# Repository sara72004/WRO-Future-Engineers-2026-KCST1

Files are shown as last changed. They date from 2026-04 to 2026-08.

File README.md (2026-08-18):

# ✨ WRO Future Engineers 2026 – Team KCST1: Blaze Autonomous Robot

##  Unleashing Blaze: Precision, Speed, and Innovation in Autonomous Robotics

Welcome to the official repository for **Blaze**, our cutting-edge autonomous robot designed and developed for the **World Robot Olympiad (WRO) 2026 – Future Engineers category**. Blaze is not just a robot; it's a testament to meticulous engineering, innovative problem-solving, and relentless pursuit of excellence. Our mission: to achieve **unparalleled robust, repeatable, and stable navigation** within a dynamic arena, powered by a sophisticated blend of laser-based environmental sensing, advanced steering control, and deterministic decision-making algorithms.

### Why "Blaze"?

Our robot's name, **Blaze**, encapsulates its core attributes and our team's aspirations:

*    **Blazing Speed:** Fast and decisive movement across the competition track.
*    **Blazing Performance:** Strong, stable, and consistent execution under pressure.
*    **Blazing Innovation:** A beacon of engineering ingenuity, pushing the boundaries of autonomous navigation.

Blaze is the culmination of countless hours of iterative design, rigorous testing, and continuous refinement, integrating state-of-the-art mechanical improvements, optimized sensor fusion, and intelligent control logic to deliver a truly competition-winning performance.

:)  *Fun note:* The name "Blaze" was chosen by a doctor ⠮⠺⠊⠎⠑⠍⠁⠝ who has supported and encouraged our team, a small detail that makes the project even more meaningful to us.

##  Meet the Innovators: Team KCST1

<div align="center">

<table>
<tr>
<td align="center">

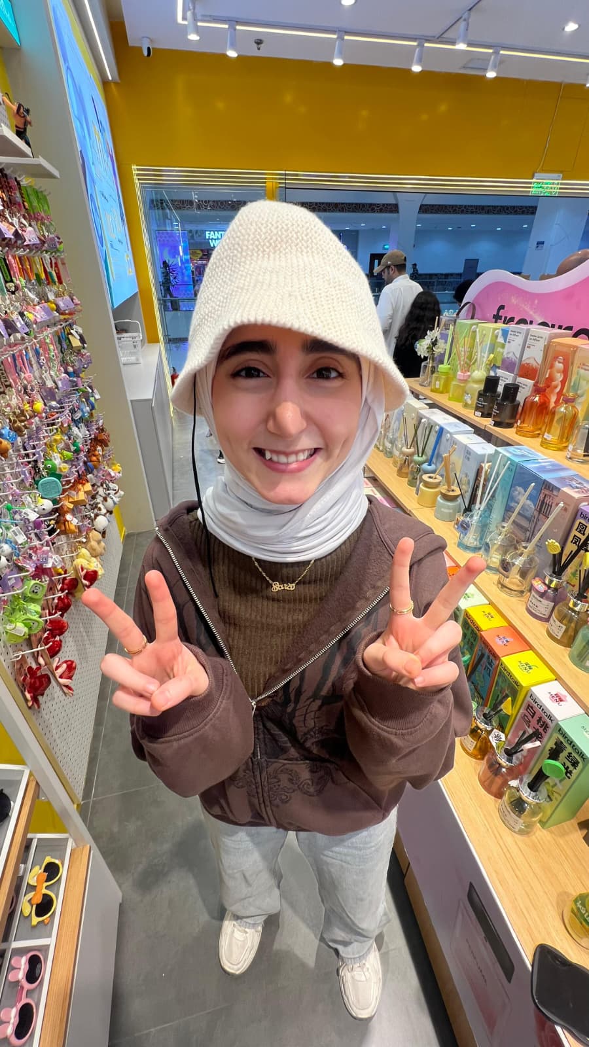
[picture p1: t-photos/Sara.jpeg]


**Sara**  
*Hardware Design, Mechanical Integration, GitHub Management*

</td>

<td align="center">

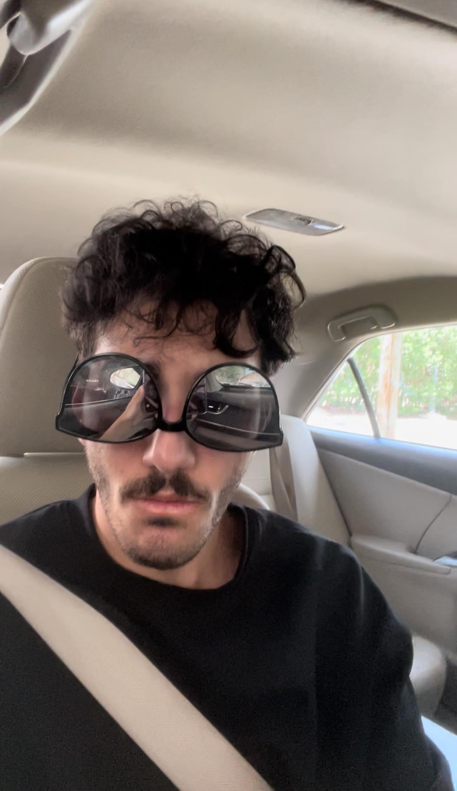
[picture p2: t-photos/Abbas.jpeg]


**Abbas**  
*Software Development, Testing, System Validation*

</td>
</tr>
</table>

</div>

---

###  Our Guiding Light: Coach Eng. Zainab

We extend our deepest gratitude to Eng. Zainab, whose invaluable guidance, unwavering support, and insightful feedback were instrumental in shaping Blaze into the formidable machine it is today.

### Team
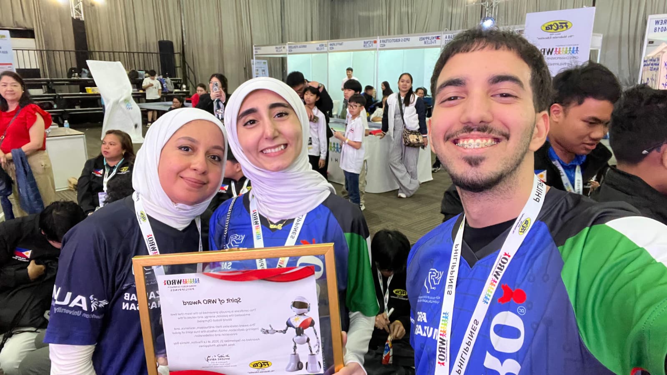
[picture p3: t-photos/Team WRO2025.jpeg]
Team


---

##  Witness Blaze in Action: Demonstration Video

Experience Blaze's autonomous capabilities firsthand:

👉 [WRO Future Engineers 2026 - Team KCST1 Robot Demonstration Video](https://youtu.be/j1B9A54QlEQ )

---

##  The Engineering Imperative: Blaze's Core Objectives

Our primary engineering objective was to construct a robot capable of:

*   **Autonomous Wall & Corner Navigation:** Seamlessly detecting and navigating complex track layouts.
*   **Stable & Responsive Steering:** Maintaining precise control across varying speeds and terrains.
*   **Consistent Lap Completion:** Reliably finishing multiple laps without human intervention.
*   **High Reliability:** Performing flawlessly under the demanding conditions of real-world competition.

---

##  Hardware Architecture: The Foundation of Performance

Blaze's robust hardware architecture is meticulously designed for optimal performance and reliability.

###  The Brain: MATRIX Mini R4 Controller

<div align="center">
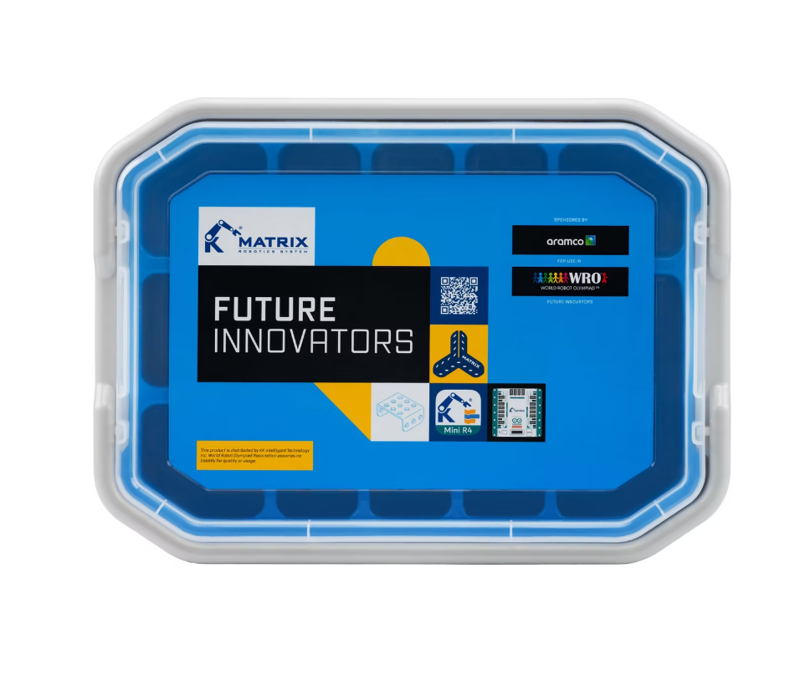
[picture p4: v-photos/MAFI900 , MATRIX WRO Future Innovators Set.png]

</div>

At the heart of Blaze lies the **MATRIX Mini R4 (MAFI900 kit)**, serving as the central processing unit, orchestrating all sensor inputs and motor outputs with precision.

---

###  The Eyes & Ears: Advanced Sensor System

<div align="center">
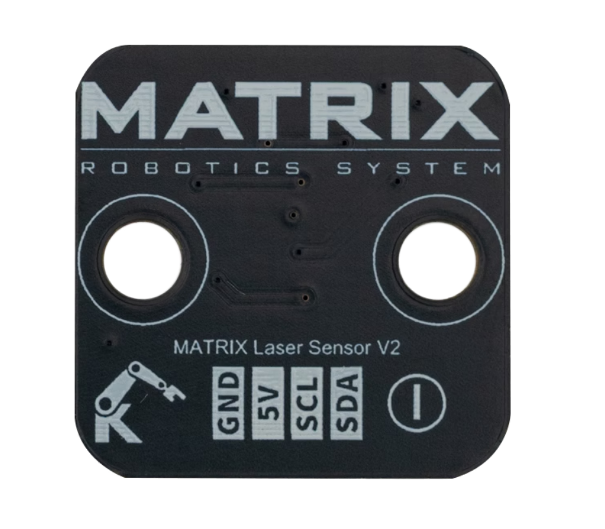
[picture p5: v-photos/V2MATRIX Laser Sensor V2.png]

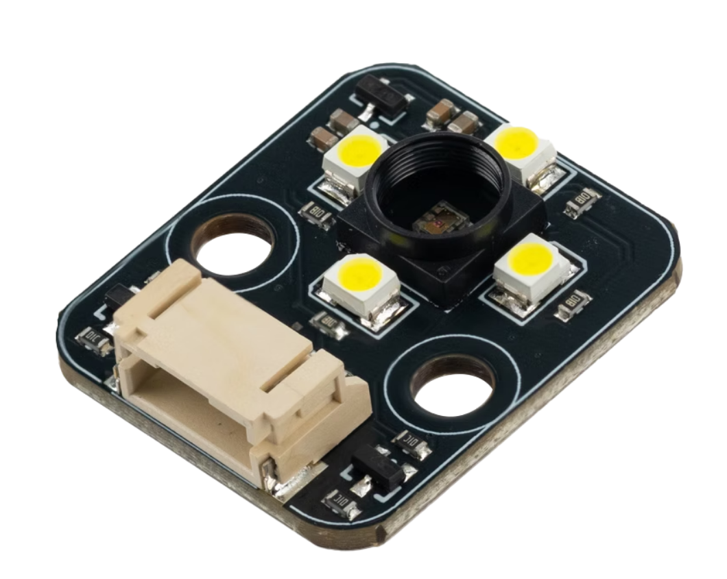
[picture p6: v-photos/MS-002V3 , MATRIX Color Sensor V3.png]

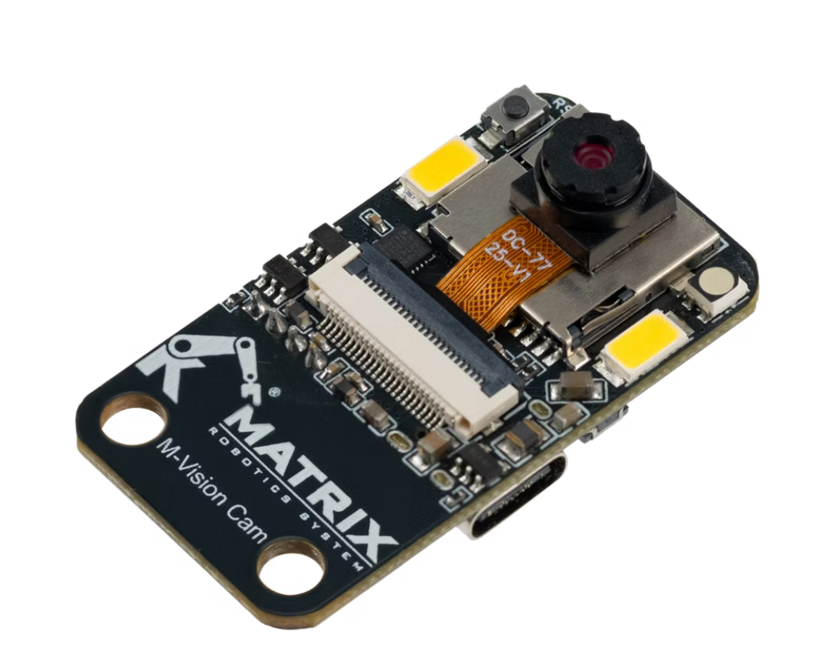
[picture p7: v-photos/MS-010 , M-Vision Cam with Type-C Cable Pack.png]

</div>

Our sensor suite provides Blaze with comprehensive environmental awareness:

*   **3 × MATRIX Laser Sensor V2:** Strategically positioned for superior reliability and consistency in distance measurement, crucial for accurate wall detection and navigation, regardless of lighting conditions.
*   **MATRIX Color Sensor V3:** Utilized for initial track detection and identifying specific colored markers, ensuring precise alignment.
*   **M-Vision Camera (MS-010):** Provides broader environmental awareness, enabling advanced decision-making for obstacle recognition and path planning.

 Laser sensors chosen for reliability and consistency.

---

###  The Muscles: Actuation System

<div align="center">
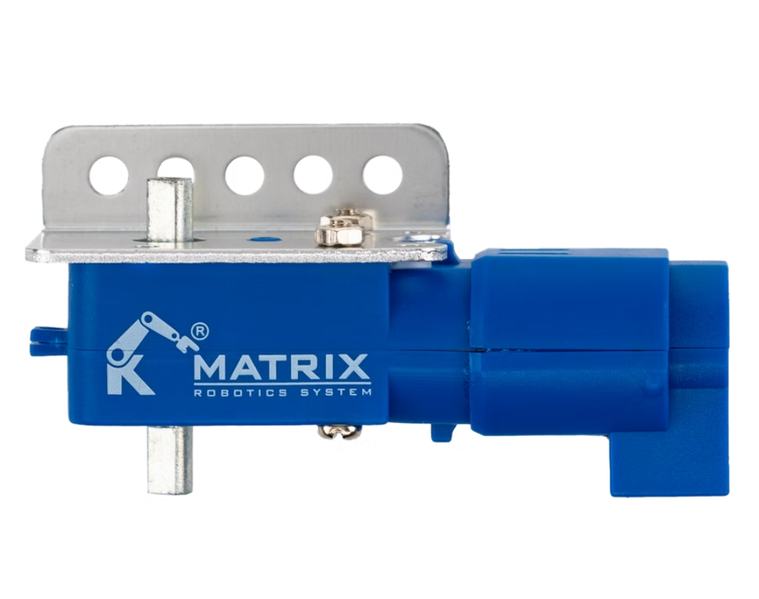
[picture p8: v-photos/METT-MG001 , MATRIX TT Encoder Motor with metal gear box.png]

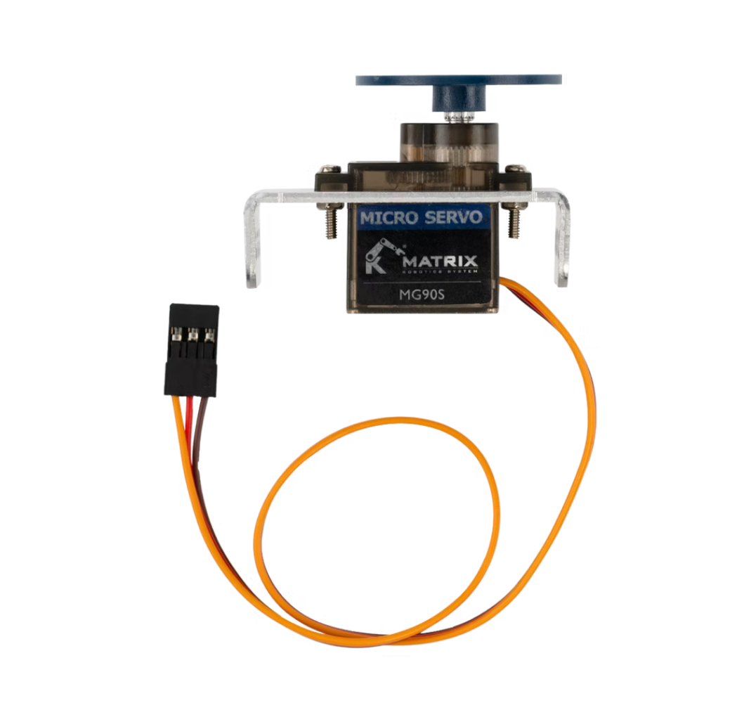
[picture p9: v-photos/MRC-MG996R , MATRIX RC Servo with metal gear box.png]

</div>

*   **TT Encoder Motors (x2):** Deliver precise control over wheel rotation and speed, essential for accurate steering and consistent movement.
*   **MG996R Servo Motor:** Provides high torque and rapid response for dynamic steering adjustments.

---

###  The Grip: Optimized Wheel System

<div align="center">
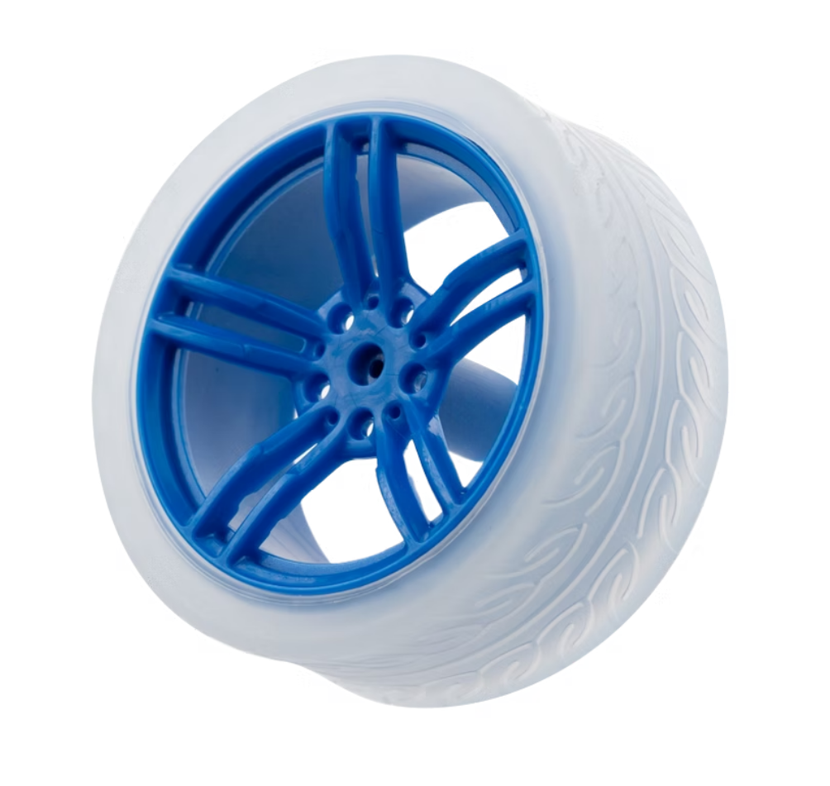
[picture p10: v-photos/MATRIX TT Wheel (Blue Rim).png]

</div>

*   **MATRIX TT Wheels:** Selected for their optimal grip and durability on the competition surface. Extensive testing revealed that a uniform wheel system significantly improves stability and predictability compared to mixed configurations.

 Improved stability after replacing mixed wheels.

---

###  Mechanical Innovation: The Custom 3D Printed Axle

<div align="center">
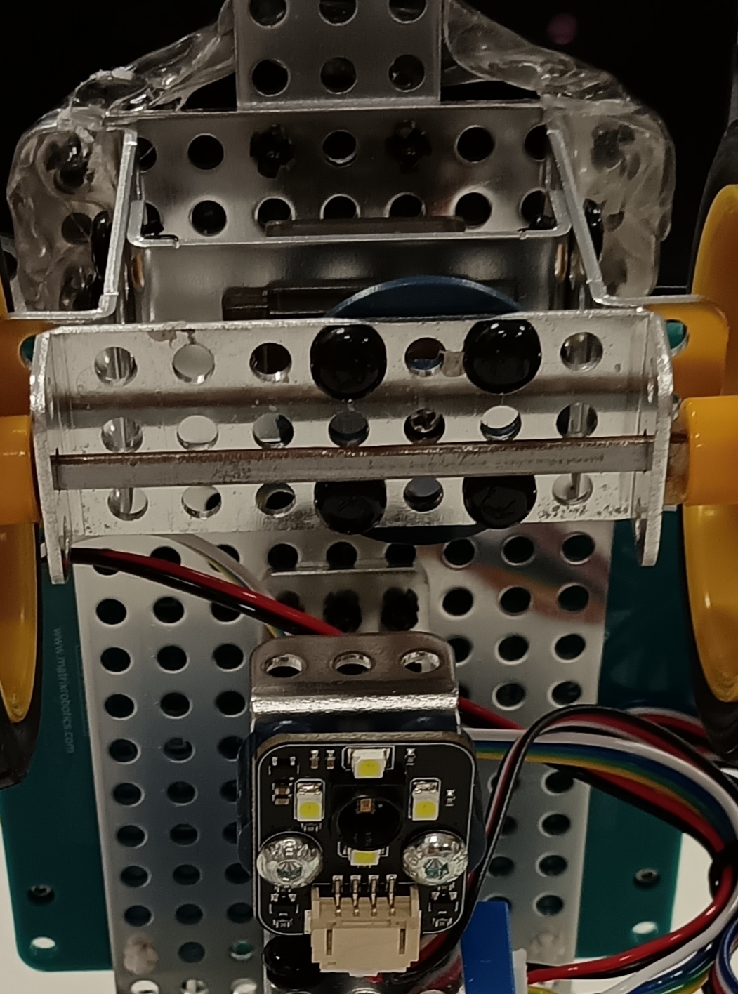
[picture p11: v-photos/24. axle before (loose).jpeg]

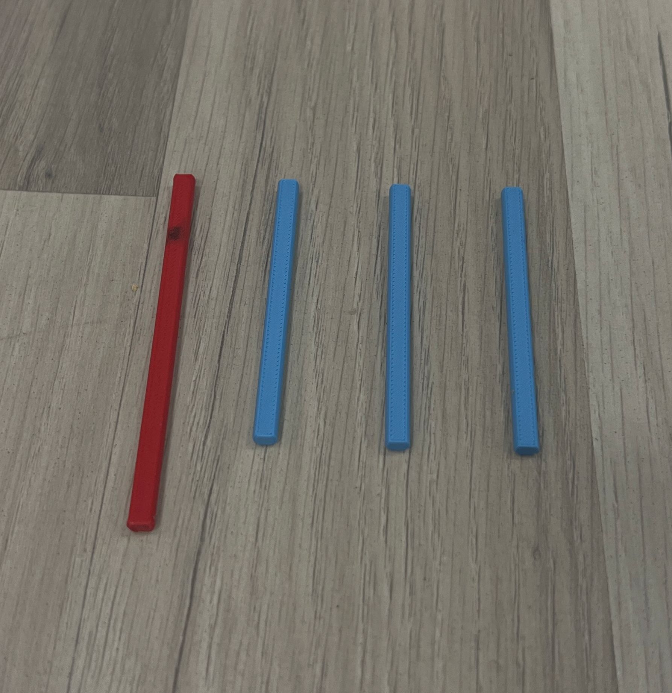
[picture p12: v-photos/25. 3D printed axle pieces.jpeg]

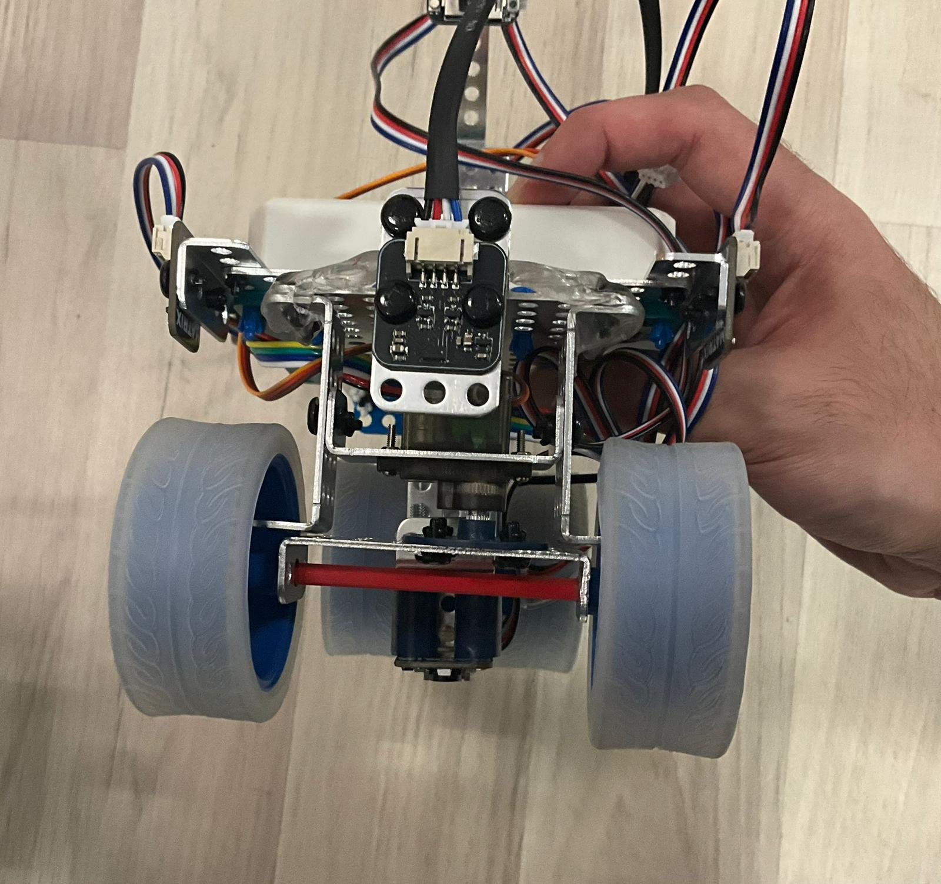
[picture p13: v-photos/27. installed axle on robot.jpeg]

</div>

#### The Challenge:

Early prototypes struggled with a loose axle, leading to unstable steering and compromised accuracy during turns, severely impacting lap times and overall performance.

#### The Breakthrough Solution:

We engineered and implemented a **custom 3D printed axle**. This innovative design provides a secure and precise fit, eliminating play and dramatically enhancing steering stability and control. The CAD files for this critical component are available in the `mechanical/CAD` directory, ensuring full reproducibility.

 Result: A significant leap in steering precision and stability, directly translating to improved navigation and reduced error rates.

---

##  System Architecture Overview

This diagram illustrates the interconnectedness of Blaze's subsystems, from power distribution to sensing and actuation.

<div align="center">
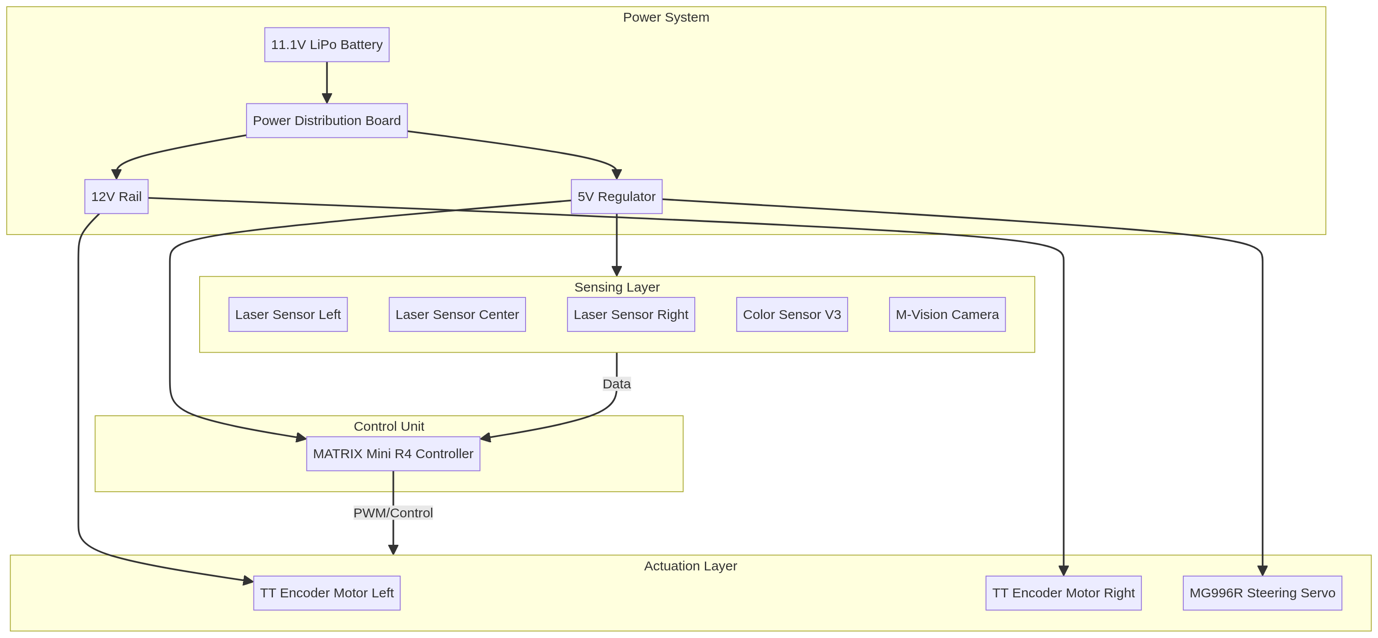
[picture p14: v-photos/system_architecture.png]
  
</div>

---

##  Navigation System Design: From Challenge to Precision

### ❌ The Initial Detour: Color-Based Navigation

<div align="center">
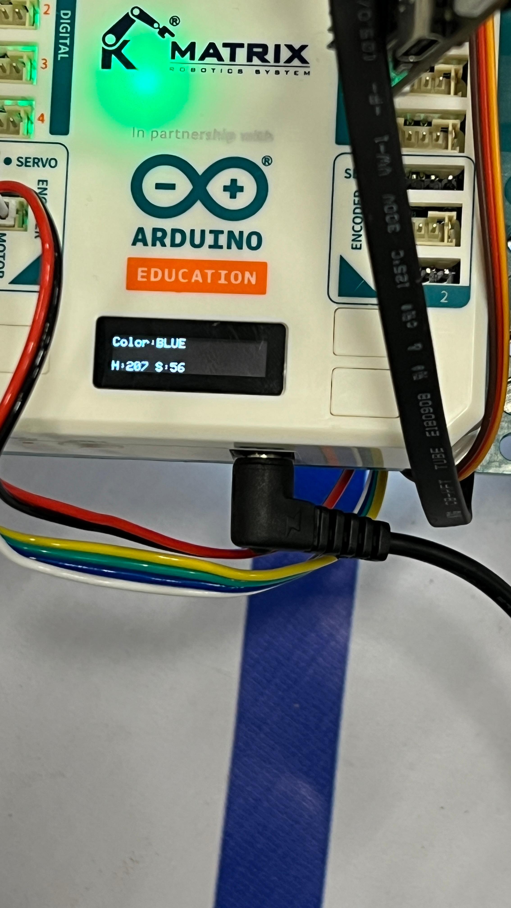
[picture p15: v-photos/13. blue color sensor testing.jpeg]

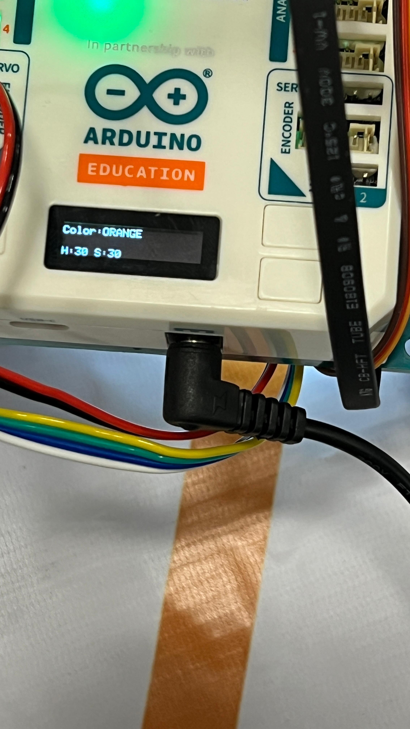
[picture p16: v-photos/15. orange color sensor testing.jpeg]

</div>

Our initial exploration into color-based navigation revealed critical limitations:

*   **Frequent Missed Detections:** Inconsistent recognition of track lines and obstacles, especially at higher speeds.
*   **Lighting Sensitivity:** Performance heavily reliant on ambient light, leading to unpredictable behavior across different environments.
*   **Inconsistent Runs:** High variability in detection resulted in unreliable lap completions.

---

### ✅ The Optimal Path: Laser-Based Navigation

Learning from these challenges, we pivoted to a laser-based system, offering decisive advantages:

*   **Unwavering Reliability:** Consistent and accurate distance readings, independent of surface color or texture.
*   **Environmental Robustness:** Stable operation across diverse lighting conditions, ensuring predictable performance.
*   **Repeatable Precision:** Eliminates variability, leading to highly predictable and repeatable robot behavior.

---

##  Design Trade-offs

We initially considered using color-based navigation due to its simplicity. However, testing revealed sensitivity to lighting conditions and missed detections at higher speeds.

Laser sensors were selected instead because they provide:
- Faster response time
- Consistent readings regardless of lighting
- More reliable wall detection for high-speed navigation
  
---

###  The Direction Locking Strategy

To prevent oscillation and ensure smooth, efficient navigation, we implemented a sophisticated direction locking strategy:

*   The robot's initial turn in any section establishes its intended direction of travel.
*   All subsequent turns within that section are then constrained to follow this established direction.

✔ Result: This strategy effectively eliminates confusion and oscillation, contributing to exceptionally smooth and efficient navigation.

---

##  Software Architecture: The Brains Behind the Blaze

Blaze's software architecture is designed for modularity, flexibility, and robust decision-making, utilizing a state machine approach for clear control flow.

### Software State Machine Diagram

This diagram visualizes the robot's operational states and transitions, providing a clear understanding of its decision-making process.

<div align="center">
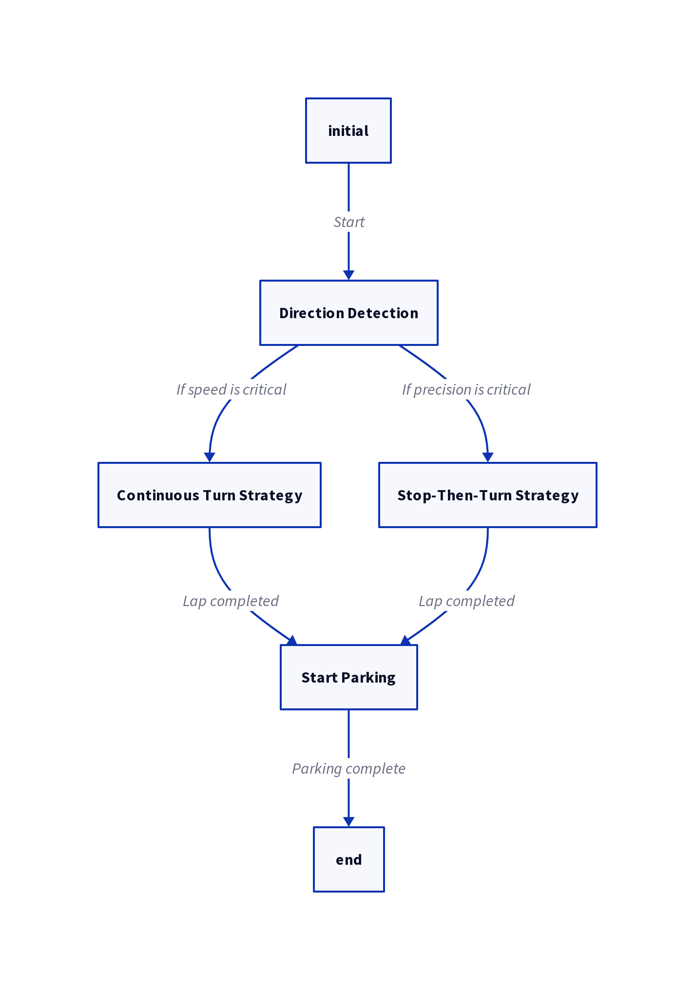
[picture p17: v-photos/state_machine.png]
  
</div>

### Navigation Logic Flowchart

This flowchart details the decision-making process for Blaze's navigation, including sensor checks and obstacle handling.

<div align="center">
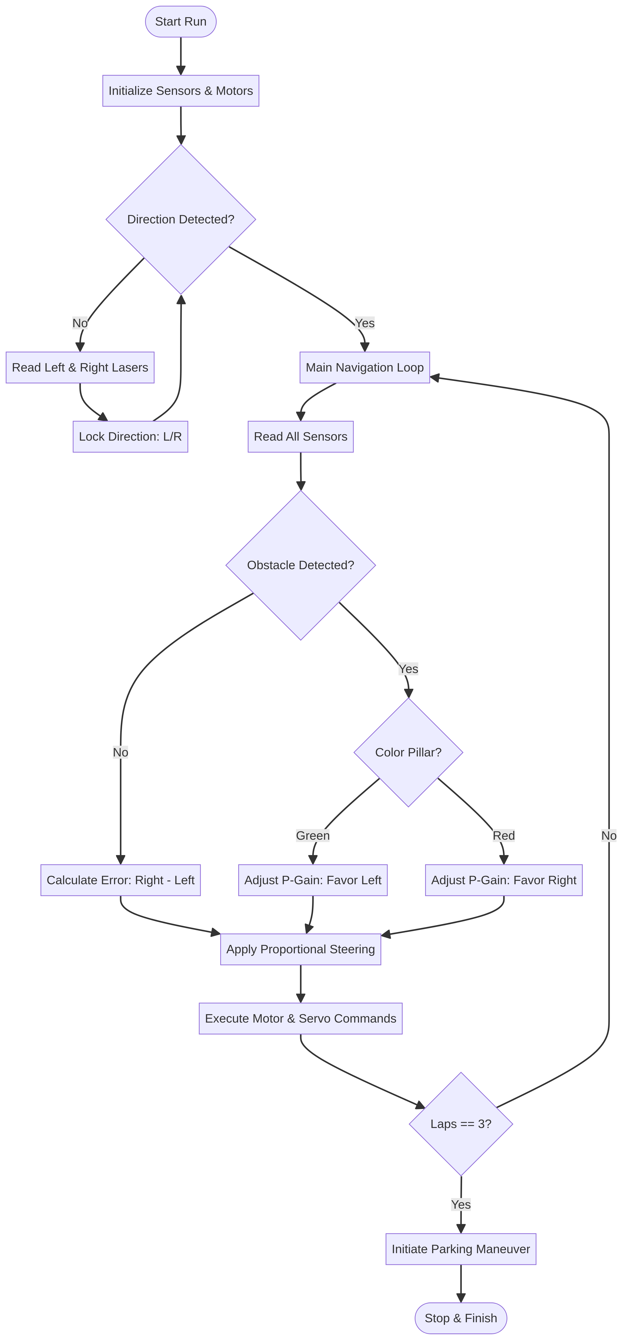
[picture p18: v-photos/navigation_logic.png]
  
</div>

### Navigation Strategies: Speed vs. Precision

We developed and implemented two distinct navigation strategies, offering tactical flexibility:
*   **🅰️ Stop-Then-Turn Strategy:**
    *   **Description:** The robot comes to a complete stop before executing a turn, prioritizing accuracy and control.
    *   **Advantages:** High accuracy, minimal overshoot, precise positioning.
    *   **Disadvantages:** Slower overall speed due to frequent stops.

*   **🅱️ Continuous Turn Strategy:**
    *   **Description:** The robot executes turns while maintaining continuous forward motion, prioritizing speed.
    *   **Advantages:** Faster lap times due to uninterrupted movement.
    *   **Disadvantages:** May exhibit slight drift or wider turning radius, potentially impacting precision.

Both strategies are available in the `src/` folder, allowing the team to select the optimal approach based on specific competition challenges and desired performance characteristics.

---

###  Final Strategy
Both approaches kept for flexibility during competition  

---

##  Source Code

The complete implementation is available in the `src/` folder.

The final code used for the Open Challenge is:

```text
open_challenge_final_pid_wall_following.ino

Example logic:

if (clockwiseMode)
{
    // Follow left wall
}
else
{
    // Follow right wall
}
```
---

##  Testing & Validation

<div align="center">
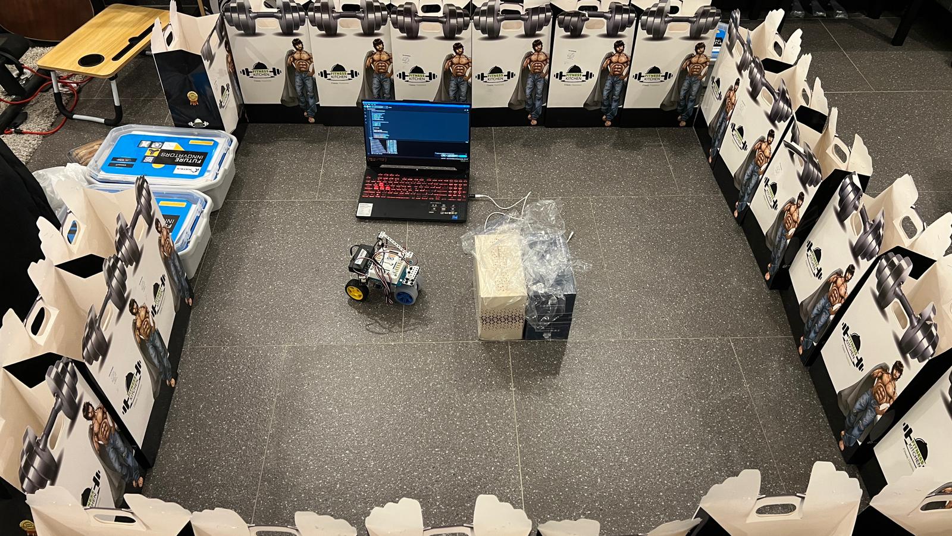
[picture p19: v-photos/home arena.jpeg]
  
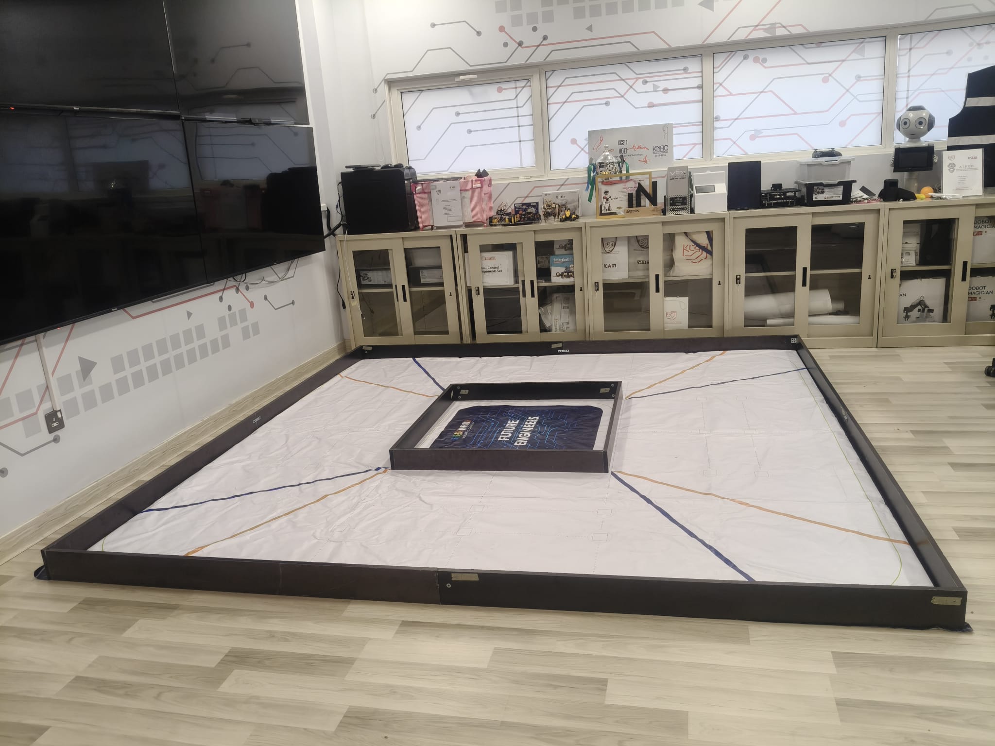
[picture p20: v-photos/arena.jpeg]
  
</div>

- Built a custom home arena  
- Simulated competition conditions  

 Enabled continuous testing

---

##  Final Robot Design

<div align="center">
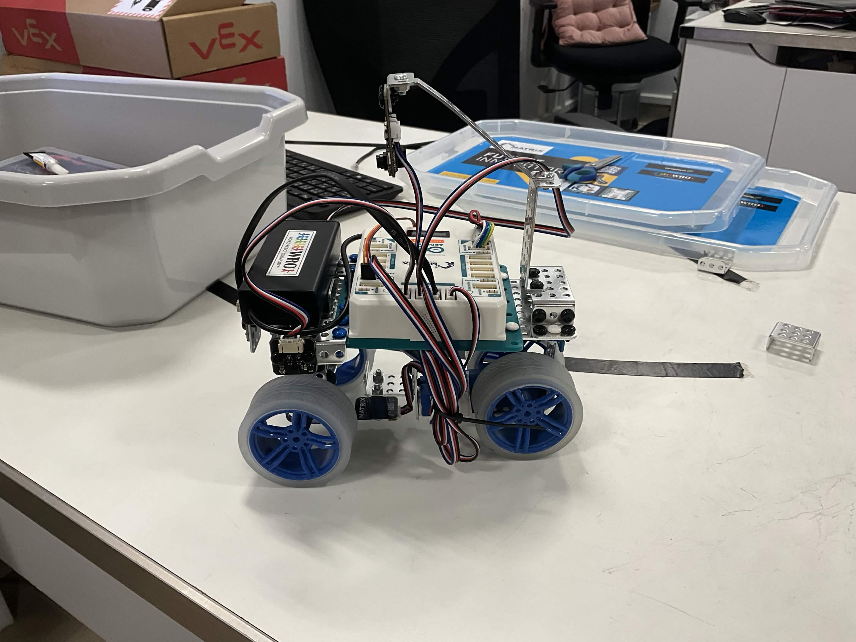
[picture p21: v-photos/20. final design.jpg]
  
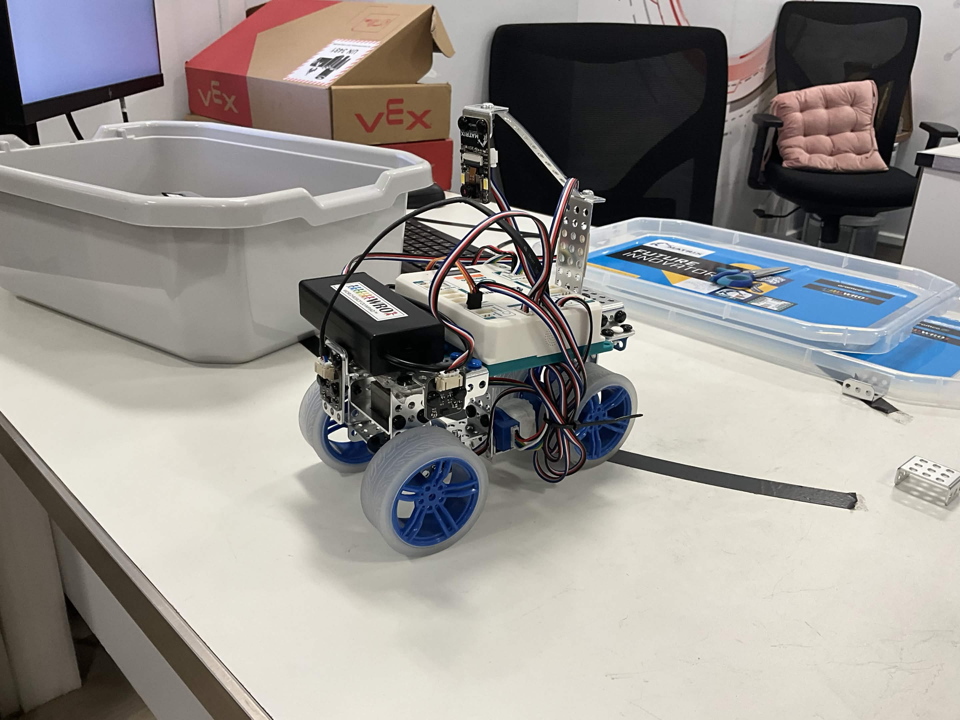
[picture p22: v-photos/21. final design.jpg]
  
</div>

###  Robot Name: Blaze

The final system is officially named **Blaze**, representing the robot’s ability to navigate quickly and reliably while maintaining control and stability.

### Key Improvements:
- Uniform wheel system  
- Custom 3D printed axle  
- Optimized sensor placement  
- Stable chassis design  

 Achieved balance between **speed, stability, and reliability**

---

##  Repository Structure: Your Guide to Blaze

Our GitHub repository is organized to provide a clear and complete overview of the project:

- `engineering_journal/` – Detailed documentation of the engineering process, design decisions, and iterations  
- `hardware/` – Electronic components, specifications, and power system  
- `mechanical/` – CAD files, 3D printed parts, and mechanical design  
- `schemes/` – System block diagrams and wiring diagrams  
- `software/` – Software architecture and algorithm explanations  
- `src/` – Source code for the robot  
- `testing/` – Testing procedures, results, and validation  
- `t-photos/` – Team photos  
- `v-photos/` – Robot photos and design evolution  
- `video/` – Demonstration video links  

Each folder is structured to reflect a specific aspect of the engineering workflow, making it easy to understand how Blaze was designed, built, and validated.

---

##  Engineering Summary

- Iterative design improvements  
- Hardware and software optimization  
- Real-world testing validation  

---

##  Final Note

The robot achieves **stable, repeatable, and reliable autonomous navigation**, meeting WRO requirements while demonstrating strong engineering principles.

##  References

[1] World Robot Olympiad. (2026). *WRO 2026 Future Engineers – Self-Driving Cars General Rules.*

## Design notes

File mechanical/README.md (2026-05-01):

# 🔧 Mechanical Design

This section documents the mechanical structure, design decisions, and improvements made to the robot.

---

##  Chassis Design

The robot chassis was built using the MATRIX structural system. The design focuses on:

- Stability during movement  
- Proper weight distribution  
- Secure mounting of all components  

The controller, sensors, and battery are positioned to maintain balance and reduce unwanted vibrations.

---

##  Wheel System Upgrade

Initially, the robot used mixed wheel types, which caused:

- Uneven traction  
- Vibrations  
- Poor steering accuracy  

###  Improvement

All wheels were replaced with identical **MATRIX TT Wheels (Blue Rim)**.

###  Result

- Smoother motion  
- Improved traction  
- More stable steering  

---

##  Custom 3D Printed Axle

###  File
- `cad/wheel_shaft_83mm.stl`

###  Problem

After upgrading the wheels, the axle did not fit tightly inside the wheel hub, leading to:

- Loose connection  
- Wheel wobbling  
- Inconsistent steering
    <div align="center">
  

###  Solution

A custom 3D printed axle was designed to:

- Match the exact diameter of the wheel hub  
- Provide a tight and secure fit  
- Eliminate unwanted movement

  <div align="center">
  
  
</div>

###  Result

- Increased steering precision  
- Improved mechanical stability  
- More consistent robot behavior  

---

##  CAD File

The custom 3D printed axle design is included in this repository.

| File | Description |
|---|---|
| [wheel_shaft_83mm.stl](wheel_shaft_83mm.stl) | Custom 3D printed axle used to improve wheel fit and steering stability |

This part was designed after the original axle was found to be loose inside the upgraded wheel hub.

##  Design Approach

The mechanical system was developed using an **iterative engineering process**:

1. Build initial design  
2. Test performance  
3. Identify mechanical issues  
4. Apply targeted improvements  

This approach ensured continuous improvement and reliable final performance.

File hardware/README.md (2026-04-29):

# 🔧 Hardware Documentation

This folder documents the main hardware components used in Blaze, our WRO Future Engineers 2026 robot.

## Main Controller
- **MATRIX Mini R4 Controller**
- Used as the central control unit for reading sensors, processing navigation logic, and controlling the motor and steering servo.

## Sensors
- **Front Laser Sensor V2** → I2C2  
- **Right Laser Sensor V2** → I2C3  
- **Left Laser Sensor V2** → I2C4  
- **MATRIX Color Sensor V3** → I2C1  
- **M-Vision Camera** → UART  

The laser sensors are the main sensors used for the final open challenge strategy because they provide fast and consistent distance readings.

## Actuators
- **TT Encoder Motor** → M1  
  - Provides forward movement.

- **MG996R Servo Motor** → RC3  
  - Controls the steering system.

## Power
- **2 Cell 18650 Battery Box**
- Powers the MATRIX Mini R4 controller and connected components.

## Final Hardware Strategy
The final robot uses laser-based wall following with PID control. The color sensor is used for detecting blue markers for lap counting, while the camera was mainly used during development and testing.

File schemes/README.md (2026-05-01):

# ⚙️ Electromechanical Diagrams

This directory contains schematic diagrams illustrating the electromechanical system of Blaze.

---

##  System Block Diagram

<div align="center">
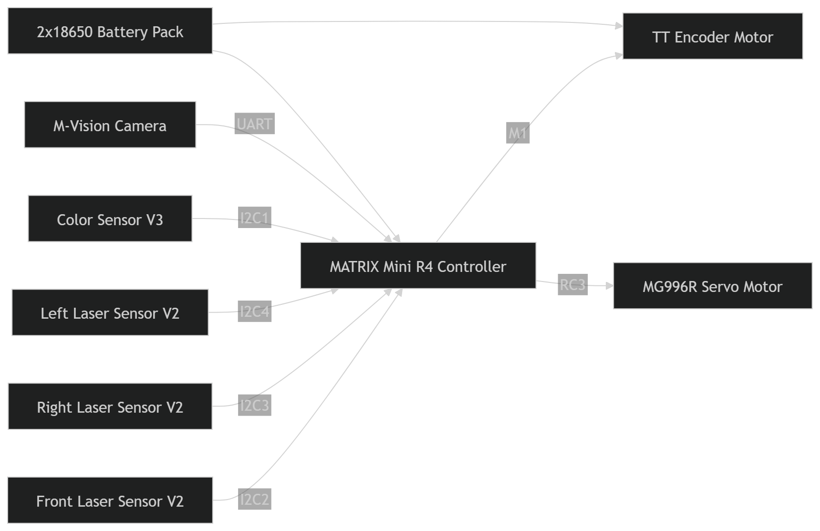
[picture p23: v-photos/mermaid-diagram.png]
  
</div>

This diagram shows the high-level system structure:
- Sensors provide input data
- MATRIX Mini R4 processes the data
- Motor and servo execute movement decisions

---

##  Wiring Diagram

<div align="center">
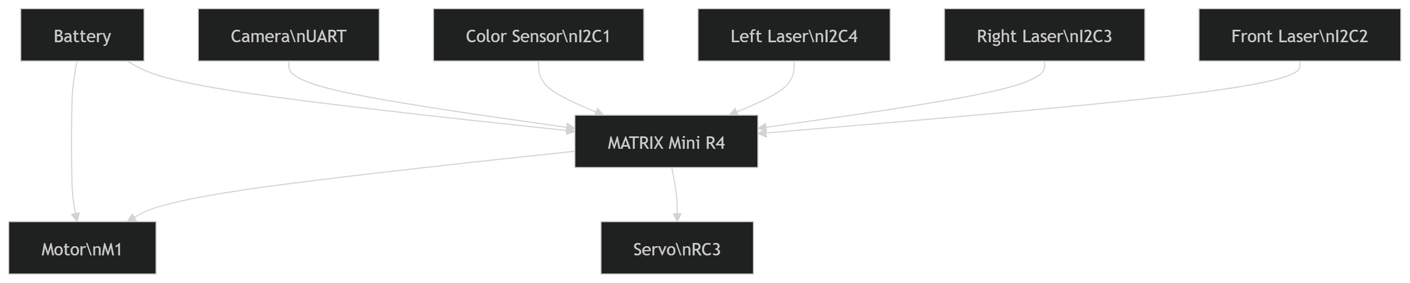
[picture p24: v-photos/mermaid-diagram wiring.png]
  
</div>

This diagram shows the wiring connections between:
- Laser sensors
- Color sensor
- M-Vision camera
- Motor
- Servo
- Battery
- MATRIX Mini R4 controller

---

##  System Architecture Diagram

This diagram explains Blaze’s complete architecture, including the power system, sensing layer, control unit, and actuation layer.

<div align="center">
  
</div>

---

##  Summary

These diagrams help explain:

- How the robot’s components are connected  
- How sensor data reaches the controller  
- How the controller sends commands to the motor and servo  
- How power is distributed across the system

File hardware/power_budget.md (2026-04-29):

# Power Budget

This document outlines the power budget for the Blaze robot, detailing the current draw and power consumption of key components. This analysis ensures that the selected power supply (LiPo battery) and voltage regulators are adequate to meet the robot's operational demands, especially during peak performance scenarios.

## Component Power Consumption

The following table summarizes the estimated current draw and power consumption for the primary electrical components of the Blaze robot:

| Component | Operating Voltage (V) | Typical Current (A) | Peak Current (A) | Power Consumption (W) |
| :--- | :--- | :--- | :--- | :--- |
| MATRIX Mini R4 (Controller) | 5 | 0.2 | 0.5 | 2.5 |
| MATRIX Laser Sensor V2 (x3) | 5 | 0.05 (each) | 0.1 (each) | 0.5 (total) |
| MATRIX Color Sensor V3 | 5 | 0.02 | 0.05 | 0.25 |
| M-Vision Camera (MS-010) | 5 | 0.1 | 0.2 | 1.0 |
| TT Encoder Motor (x2) | 12 | 0.5 (each) | 1.5 (each) | 36.0 (total peak) |
| MG996R Servo Motor | 5 | 0.1 | 0.5 | 2.5 |
| **Total Estimated Peak Consumption** | | | **~4.85** | **~42.75** |

*Note: Current and power values are approximate and can vary based on specific operating conditions and load. Peak current for motors is estimated during high-load situations (e.g., rapid acceleration or turning).*

## Power System Architecture

The robot's power system is designed around a 3-cell LiPo battery, providing a nominal voltage of 11.1V (fully charged at 12.6V). This battery feeds into a main power distribution board, which then supplies power to various components through appropriate voltage regulators:

*   **12V Line:** Directly powers the TT Encoder Motors, ensuring they receive sufficient voltage for optimal torque and speed.
*   **5V Regulator:** A dedicated 5V regulator steps down the battery voltage to supply the MATRIX Mini R4 controller, all sensors (Laser, Color, Camera), and the MG996R Servo Motor. This ensures stable and clean power for sensitive electronic components.

## Justification of Design Choices

*   **LiPo Battery Selection:** Chosen for its high energy density and discharge rate, suitable for powering the motors and electronics for extended periods during competition rounds.
*   **Voltage Regulators:** Implemented to provide stable and correct operating voltages for each component, protecting sensitive electronics from voltage fluctuations and ensuring reliable performance.
*   **Current Draw Reasoning:** The total estimated peak current draw of approximately 4.85A (primarily driven by the motors) is well within the safe operating limits of the selected LiPo battery and voltage regulators, which are rated to handle higher continuous and peak currents. This prevents overheating and ensures consistent power delivery.

This detailed power budget analysis confirms the robustness of our power system architecture, minimizing the risk of power-related failures during critical competition moments.

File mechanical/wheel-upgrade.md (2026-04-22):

# Wheel Upgrade

The original front wheels were yellow wheels, but they caused shaking and instability. They were replaced with wheels matching the rear wheels.

This improved:
- stability
- consistency of friction
- steering smoothness
- overall appearance

A remaining issue is the loose axle fit inside the wheel. The planned fix is either a 3D-printed axle insert or another secure fitting method.

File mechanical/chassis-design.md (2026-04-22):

# Chassis Design

The robot uses a rear-wheel-drive design. A single motor drives the rear axle, while the front wheels are connected through a steering axle controlled by a servo motor.

The motor was mounted using metal brackets to create a stable box-like support structure connected to the main chassis.

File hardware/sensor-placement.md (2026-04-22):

# Sensor Placement

- Front laser sensor: detects wall or obstacle in front
- Left laser sensor: measures distance to the left side
- Right laser sensor: measures distance to the right side

- Color sensor (bottom-mounted):
  The color sensor is placed facing downward toward the floor.
  It is used to detect floor colors (blue and orange) at the start of the run.

  This allows the robot to:
  - Determine the initial direction (clockwise or counterclockwise)
  - Maintain consistent navigation behavior throughout the lap

- Camera:
  Mounted above the robot to detect colored obstacle blocks (red and green)

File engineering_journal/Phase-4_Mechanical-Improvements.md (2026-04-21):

# Phase 4 – Mechanical Improvements

## Problem

The original front wheels (yellow wheels) caused:

* Shaking
* Uneven movement
* Reduced stability

## Solution

* Replaced front wheels with same type as rear wheels
* Ensured consistent friction across all wheels

## New Issue

* Axle became loose inside the wheel

## Planned Fix

* 3D printed custom axle (preferred)
* Backup: secure with adhesive

## Result

Improved stability and smoother movement.

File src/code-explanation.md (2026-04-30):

# Code Explanation

Two navigation strategies were developed and tested.

## 1. Stop-Before-Turn (stop_before_turn.ino)
- The robot stops briefly before turning
- Reduces drift
- More accurate turns
- Slightly slower

## 2. Continuous Turning (continuous_turn.ino)
- The robot keeps moving while turning
- Faster movement
- May introduce slight drift

## 3. Reverse-and-Turn Navigation Strategy
This version of the code stops the robot when a wall is detected, reverses slightly, and then performs the turn. This strategy was developed to improve turning space and reduce steering errors when the robot approaches walls too closely.

# Final Open Challenge Code Explanation

The final open challenge code uses a faster and more stable control strategy than the earlier timed-turn versions. Instead of only waiting for a front wall and performing a fixed turn, this version continuously follows one side wall using PID control while also using a front-wall override for corners.

## Main Strategy

The robot can run in two directions:

- **Clockwise (CW)**: follows the left wall
- **Counter-clockwise (CCW)**: follows the right wall

Before starting, the direction can be changed using the UP button. The robot starts when the DOWN button is pressed.

## Sensor Usage

The robot uses:

- **Front Laser Sensor (I2C2)**: detects upcoming walls and corners
- **Right Laser Sensor (I2C3)**: used for right-wall following
- **Left Laser Sensor (I2C4)**: used for left-wall following
- **Color Sensor V3 (I2C1)**: detects blue floor markers for lap/turn counting

## PID Wall Following

During normal driving, the robot follows one side wall using PID control.

The PID controller compares the measured wall distance with the target wall distance. The difference becomes the error. The controller then calculates a steering correction to keep the robot at a stable distance from the wall.

This makes the robot smoother and more responsive than the earlier fixed-timing codes.

## Front Wall Avoidance

When the front sensor detects a wall, the robot temporarily overrides normal PID wall following and performs a timed steering action.

The closer the wall is, the stronger the steering correction becomes.

This helps the robot handle corners more reliably without waiting too long or crashing into the wall.

## Servo Smoothing

The servo does not instantly jump to the target angle. Instead, it moves gradually toward the target. This reduces shaking, improves stability, and prevents sudden steering movements.

During front-wall avoidance, the servo response is temporarily increased so the robot can turn faster at corners.

## Speed Adjustment

The robot reduces speed when the steering angle becomes large. This helps reduce drift and keeps the robot stable during sharper corrections.

## Lap Counting

The color sensor detects blue floor markers. The robot counts a blue marker only when it first appears, and a cooldown is used to prevent counting the same marker multiple times.

When the required number of blue detections is reached, the robot stops.

## Why This Code Replaced the Earlier Versions

Earlier versions used fixed turn sequences such as:

- stop-then-turn
- continuous turn
- stop-reverse-then-turn

Those versions worked, but they were less adaptive. This final version performs better because it continuously corrects its path using sensor feedback, making it smoother, faster, and more reliable for the open challenge.

---

## Obstacle Challenge Camera Code Explanation

This code is used for the **Obstacle Challenge**. It is the most advanced version because it combines laser wall-following, camera obstacle detection, front-wall avoidance, and reverse recovery.

### Main Idea

The robot normally follows the arena wall using PID control. When the camera detects a red or green obstacle, the robot changes its steering to pass the obstacle from the correct side:

- **Red obstacle** → pass on the **right**
- **Green obstacle** → pass on the **left**

The code also includes a safety recovery system that reverses the robot if it gets too close to a wall or obstacle.

---

### Sensor Ports

- `I2C1` → Color Sensor V3
- `I2C2` → Front Laser Sensor
- `I2C3` → Right Laser Sensor
- `I2C4` → Left Laser Sensor
- `Serial1` → M-Vision Camera UART data

---

### Actuator Ports

- `M1` → TT Encoder Motor
- `RC3` → Steering Servo

---

### Camera Packet

The camera sends obstacle data in this format:

```text
seen,color,cx,cy,w,h,score,zone
```
---

### Control Priority System

The robot follows a priority-based decision system to ensure safe and reliable navigation.

1. Reverse Recovery  
   Activated when the robot is too close to a wall or obstacle. The robot reverses and repositions itself.

2. Camera Obstacle Guidance  
   When a valid red or green obstacle is detected, the robot adjusts its path to pass on the correct side.

3. Front Wall Assist  
   If the front laser detects a wall, the robot performs a temporary steering correction to avoid collision.

4. Normal PID Wall Following  
   Default behavior when no obstacles or hazards are present.

   ### PID Control System

The robot uses a PID controller to maintain a stable distance from the wall.

- Proportional (P): reacts to the current error between target distance and actual distance  
- Integral (I): corrects accumulated small errors over time  
- Derivative (D): reduces overshooting and stabilizes motion  

This allows smooth and accurate wall-following instead of sharp or unstable steering.

### System Advantages

This implementation improves performance compared to simpler approaches by combining:

- Sensor fusion (camera + laser sensors)
- Adaptive steering using PID control
- Reverse recovery for safety
- Obstacle-aware navigation
- Servo smoothing for stability

These features allow the robot to handle real competition conditions more reliably.

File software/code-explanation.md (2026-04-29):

# Software Architecture and Obstacle Strategy

This document details the software architecture and the strategies implemented for obstacle avoidance and navigation for the Blaze robot. The software is designed with modularity and flexibility in mind, allowing for easy adaptation to different challenge scenarios and continuous improvement.

## 1. Overall Software Architecture

The core navigation logic is implemented using a **state machine approach**, which provides a clear and structured way to manage the robot's behavior based on its current environment and mission objectives. The state machine transitions are triggered by sensor inputs and internal logic, ensuring robust and predictable operation.

### State Machine Diagram

<div align="center">
  
</div>

**Explanation of States:**

*   **Initial:** The starting state of the robot, awaiting activation.
*   **Direction Detection:** The robot determines the initial direction of travel (clockwise or counter-clockwise) based on predefined criteria or sensor readings. This decision is crucial for consistent lap completion.
*   **Continuous Turn Strategy:** If speed is prioritized, the robot enters this state, executing turns while maintaining continuous forward motion. This strategy is optimized for faster lap times.
*   **Stop-Then-Turn Strategy:** If precision is critical, the robot enters this state, coming to a complete stop before executing a turn. This ensures high accuracy and minimal overshoot.
*   **Lap Completed:** After completing the required number of laps, the robot transitions to this state.
*   **Start Parking:** The robot initiates the parking maneuver, aiming to precisely position itself in the designated parking lot.
*   **End:** The robot successfully completes its mission and enters a standby state.

### 5.2 Lane Following and Obstacle Obedience Strategy

Our primary navigation method relies on **laser-based environmental sensing** to detect walls and maintain a consistent distance from them. This approach offers superior reliability compared to color-based methods, especially under varying lighting conditions.

### Lane Following Algorithm

Our lane following algorithm utilizes a **proportional controller** based on the lateral offset of the detected lane center. The laser sensors provide continuous feedback on the robot's distance to the left and right walls. This information is used to calculate the robot's deviation from the center of the lane. A proportional control loop then adjusts the steering angle to minimize this deviation, keeping the robot centered within the lane.

*   **Input:** Distance readings from left and right laser sensors.
*   **Calculation:** `Error = Distance_Right - Distance_Left`
*   **Output:** Steering adjustment proportional to `Error`.

### Obstacle Obedience Strategy

For the Obstacle Challenge, the robot must interpret traffic signs (green and red pillars) and adjust its lane-following behavior accordingly. Our strategy incorporates the following logic:

*   **Green Pillar (Keep Left):** Upon detecting a green pillar, the robot temporarily adjusts its proportional control to favor the left side of the lane, maintaining a closer distance to the left wall while passing the obstacle.
*   **Red Pillar (Keep Right):** Similarly, upon detecting a red pillar, the robot adjusts its control to favor the right side of the lane, maintaining a closer distance to the right wall.
*   **Avoidance:** The laser sensors also provide data for obstacle avoidance. If an obstacle is detected directly in the robot's path, a pre-programmed avoidance maneuver is initiated, which may involve temporary deviation from the lane center, followed by a return to the lane once the obstacle is cleared.

### 5.3 Algorithms Used

*   **Proportional Control (P-Controller):** Used for lane following to maintain the robot's position relative to the lane center. The steering output is directly proportional to the error (deviation from center).
*   **State Machine Logic:** Manages the overall flow of the robot's behavior, transitioning between different operational states (e.g., direction detection, continuous turn, stop-then-turn, parking) based on sensor inputs and mission progress).
*   **Decision-Making Algorithms:** Simple conditional logic is used for obstacle obedience (green/red pillars) and for selecting between continuous turn and stop-then-turn strategies based on predefined criteria or real-time performance metrics.

### 5.4 Testing and Tuning Process

Our software was developed through an iterative process of testing and tuning, primarily conducted on a custom home arena that replicated competition conditions.

*   **Unit Testing:** Individual modules, such as sensor reading, motor control, and basic navigation functions, were tested independently to ensure their correct operation.
*   **Integration Testing:** Different software components were integrated and tested together to verify their interactions and overall system behavior.
*   **Performance Tuning:** Parameters for the proportional controller (e.g., proportional gain) were fine-tuned through extensive experimentation on the test track. Metrics such as lap consistency, speed, and accuracy of turns were used to evaluate performance.
*   **Edge Case Handling:** The robot was tested under various challenging scenarios, including tight corners, unexpected obstacles, and different lighting conditions, to identify and address potential failure modes.

This rigorous testing and tuning process allowed us to optimize the robot's performance, ensuring its stability, reliability, and ability to consistently complete the challenges.

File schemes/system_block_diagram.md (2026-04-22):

# 🧠 System Block Diagram

This diagram illustrates the **high-level architecture** of the robot and how all major components interact with the central controller.

---

## 📊 Diagram

System Block Diagram

---

## 🔍 Description

The system is centered around the **MATRIX Mini R4 Controller**, which acts as the main processing unit.

### 🧩 Input Components
The controller receives data from multiple sensors:

- **Front Laser Sensor V2 (I2C2)**  
  Detects obstacles directly ahead

- **Left Laser Sensor V2 (I2C4)**  
  Measures distance from the left wall

- **Right Laser Sensor V2 (I2C3)**  
  Measures distance from the right wall

- **Color Sensor V3 (I2C1)**  
  Detects floor colors (blue/orange) for navigation logic

- **M-Vision Camera (UART)**  
  Used during development for object detection experiments

---

### ⚙️ Output Components

The controller processes sensor data and controls actuators:

- **TT Encoder Motor (M1)**  
  Provides forward motion and speed control

- **MG996R Servo Motor (RC3)**  
  Controls steering direction

---

### 🔋 Power System

- **2x18650 Battery Pack**  
  Supplies power to the controller and all connected components

---

## 🎯 Purpose

This diagram shows the **logical flow of data and control**, helping to understand:

- How sensor data is collected  
- How decisions are made  
- How motion is executed  

---

## ✅ Summary

The system follows a simple but effective structure:

**Sensors → Controller → Decision Logic → Actuators**

This design ensures:
- Fast response time  
- Reliable navigation  
- Clear separation between sensing and control

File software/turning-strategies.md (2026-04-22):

# Turning Strategies

Two turning strategies were developed.

## 1. Stop-before-turn
The robot stops briefly before turning. This reduces drift and improves turn accuracy.

## 2. Continuous turning
The robot keeps moving while steering. This is faster but may introduce more drift.

Both versions were kept so the best one can be selected depending on competition conditions.

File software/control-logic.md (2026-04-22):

# Control Logic

The robot reads three laser sensors: front, left, and right.

Logic:
1. Move forward normally
2. Detect wall using front sensor
3. Compare left and right distances
4. Turn toward the more open side
5. First turn determines the overall lap direction
6. Continue following the same direction for the remaining turns

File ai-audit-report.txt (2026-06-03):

Team: KCST1
Robot: Blaze

AI Tool Used:
- OpenAI ChatGPT

Purpose of AI Usage:
- Improving documentation structure
- Reviewing README formatting
- Generating diagram templates
- Improving grammar and readability
- Assisting with code documentation and explanations
- Suggesting repository organization

AI was NOT used to:
- Directly control the robot during operation
- Generate final engineering decisions without verification
- Replace testing, calibration, or validation performed by the team

Example Prompts Used:

1. "Help organize a WRO Future Engineers GitHub repository according to the competition requirements."

2. "Create a README structure for a WRO Future Engineers robot named Blaze."

3. "Explain this navigation code and generate documentation comments."

4. "Generate a system block diagram and wiring diagram description."

5. "Review repository completeness according to WRO Future Engineers requirements."

Verification:
All AI-generated suggestions were reviewed, modified, tested, and validated by the team before inclusion in the repository.

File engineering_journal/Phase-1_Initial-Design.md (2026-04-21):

# Phase 1 – Initial Design

## Objective

The initial goal was to create a navigation system using a color sensor to detect floor markings (blue/orange) and determine the robot’s turning direction.

## Approach

* Blue line → turn left
* Orange line → turn right

## Result

This approach worked in controlled conditions but failed under higher speeds.

## Conclusion

Color detection alone was not reliable for competition conditions.

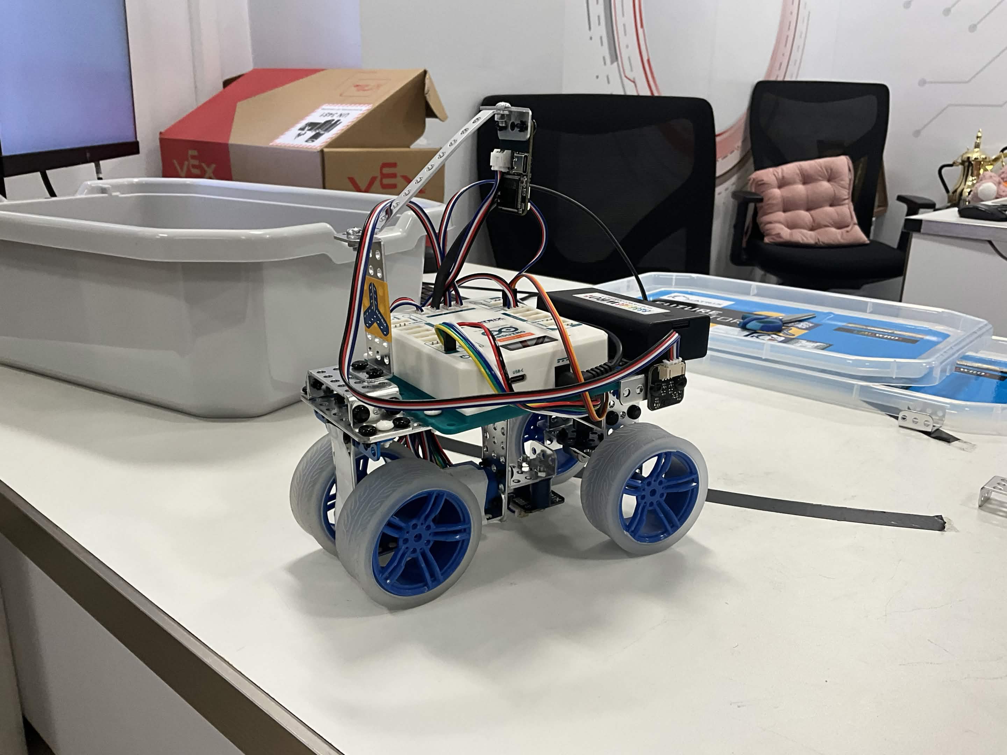
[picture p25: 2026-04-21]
v-photos/23. final design.jpg

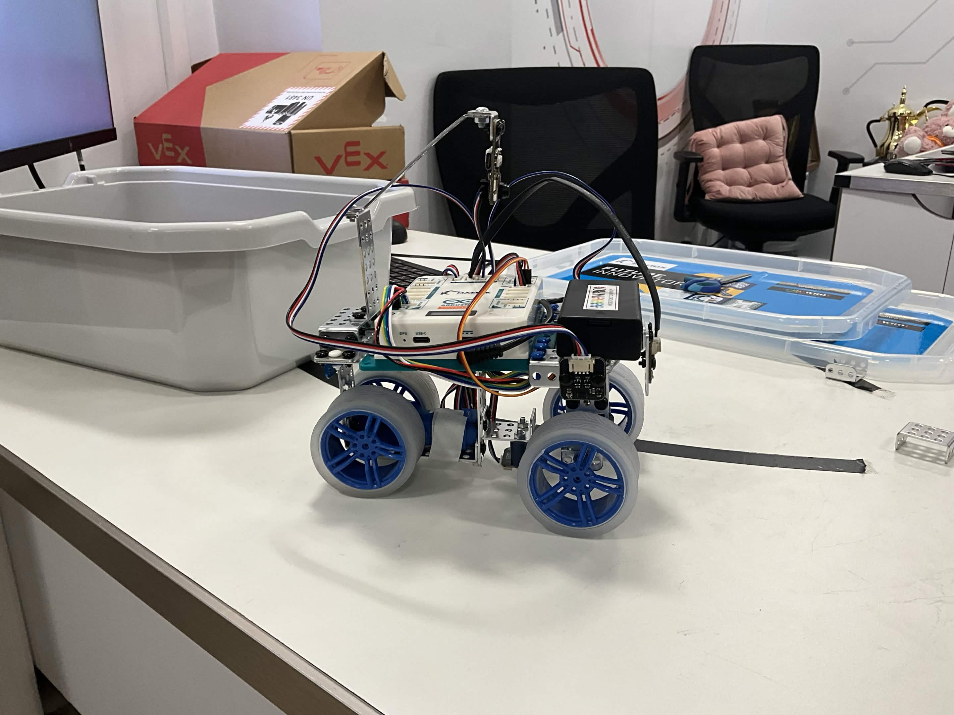
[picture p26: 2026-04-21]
v-photos/22. final design.jpg

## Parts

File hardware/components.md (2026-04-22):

##  Hardware Components

The robot was built using components from the **MATRIX WRO Future Innovators Set (MAFI900)** along with additional sensors and modules. The key hardware used in this project includes:

###  Main Controller
- **MATRIX Mini R4 (included in MAFI900 kit)**  
  Acts as the central control unit responsible for processing sensor data and controlling all actuators.

---

###  Sensors
- **MATRIX Laser Sensor V2 (×3)**  
  Used for distance measurement and wall detection (front, left, and right).

- **MATRIX Color Sensor V3 (MS-002V3)**  
  Used for detecting floor colors (blue/orange) to assist with navigation logic.

- **M-Vision Camera (MS-010)**  
  Used during development for visual detection and experimentation.

---

###  Actuators
- **MATRIX TT Encoder Motor (METT-MG001)**  
  Provides forward motion with controlled speed output.

- **MATRIX RC Servo with Metal Gearbox (MRC-MG996R)**  
  Controls steering of the front wheels with high torque and precision.

---

###  Mechanical Components
- **MATRIX TT Wheels (Blue Rim)**  
  Used for consistent traction and improved stability.

- **Chassis and Structural Parts (from MAFI900 kit)**  
  Includes metal beams, brackets, connectors, and mounting components used to assemble the robot structure.

---

###  Power System
- **2 Cell 18650 Battery Box (18650-HD)**  
  Provides stable power supply to the controller, sensors, and motors.

---

###  Additional Kit Contents (MAFI900)
The MATRIX WRO Future Innovators Set also includes:
- Structural metal parts (beams, plates, brackets)  
- Screws, nuts, spacers, and connectors  
- Cables (JST and Grove cables for sensor connections)  
- Mounting hardware for motors and sensors  

---

###  Custom Modifications
- **3D Printed Axle (Custom Design)**  
  Developed to fix looseness between the wheel and axle, improving steering precision and mechanical stability.

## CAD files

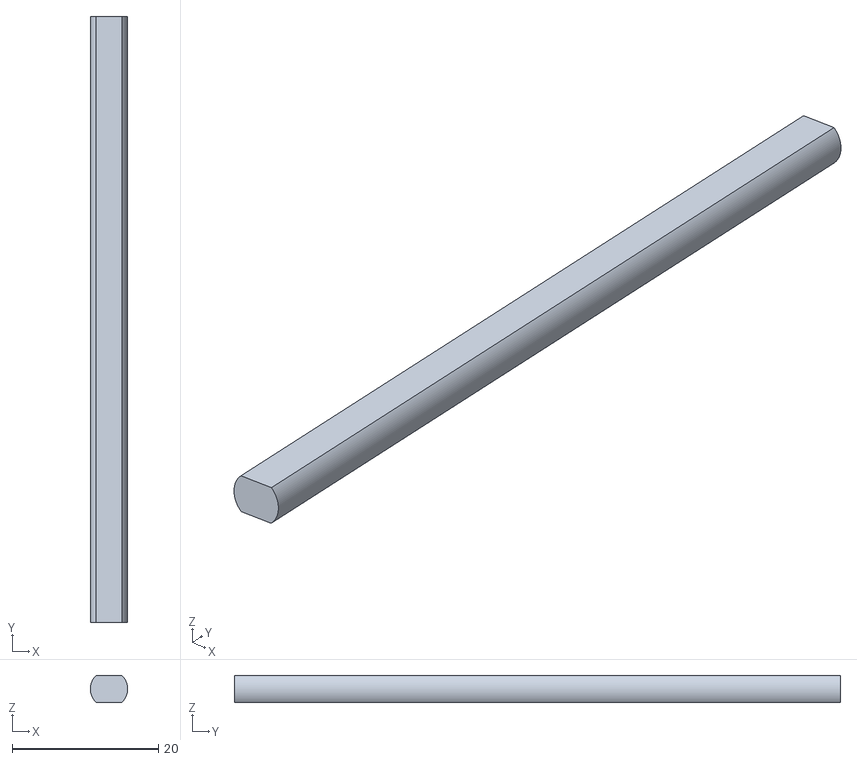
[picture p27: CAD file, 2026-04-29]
mechanical/wheel_shaft_83mm.stl
5.11 x 83.0 x 3.75

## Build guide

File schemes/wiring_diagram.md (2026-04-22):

# 🔌 Wiring Diagram

This diagram shows the **physical connections** between all electronic components and the MATRIX Mini R4 controller.

---

## 📊 Diagram

Wiring Diagram

---

## 🔍 Description

The wiring diagram provides a detailed view of how each component is connected to specific ports on the controller.

---

## ⚡ Power Connections

- **2x18650 Battery Pack → Controller Power Input**
  - Supplies power to the entire system
  - The controller distributes power to sensors and actuators

---

## 📡 Sensor Connections

### Laser Sensors (I2C Communication)

- **Front Laser Sensor → I2C2**
- **Right Laser Sensor → I2C3**
- **Left Laser Sensor → I2C4**

✔ These sensors provide real-time distance measurements for navigation.

---

### Color Sensor

- **Color Sensor V3 → I2C1**

✔ Used for detecting floor colors and determining movement direction.

---

### Camera Module

- **M-Vision Camera → UART Port**

✔ Used during development for object detection and testing.

---

## ⚙️ Actuator Connections

### Motor

- **TT Encoder Motor → M1 Port**

✔ Controls forward movement and speed.

---

### Steering

- **MG996R Servo Motor → RC3 Port**

✔ Controls the steering angle of the robot.

---

## 🎯 Purpose

This diagram helps to:

- Ensure correct hardware assembly  
- Avoid incorrect wiring during setup  
- Provide a reference for troubleshooting  

---

## ✅ Summary

The wiring design ensures:

- Clean and organized connections  
- Proper communication between components  
- Reliable power distribution  

All connections are made directly to the **MATRIX Mini R4**, making the system simple and efficient.

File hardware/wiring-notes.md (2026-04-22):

# Wiring Notes

## Motors and Actuators
- M1: rear drive motor (controls forward movement)
- RC3: steering servo motor (controls front wheel direction)

## Laser Sensors
- I2C2: front laser sensor (detects walls or obstacles ahead)
- I2C3: right laser sensor (measures distance from the right side)
- I2C4: left laser sensor (measures distance from the left side)

## Color Sensor
- Model: MXColor Sensor V2
- Port: I2C1
- Mounted underneath the robot facing the ground
- Used to detect blue and orange floor colors to determine the initial navigation direction

## Camera
- Connected via UART port
- Mounted above the robot using a custom bracket
- Used to detect red and green obstacle blocks during the obstacle challenge

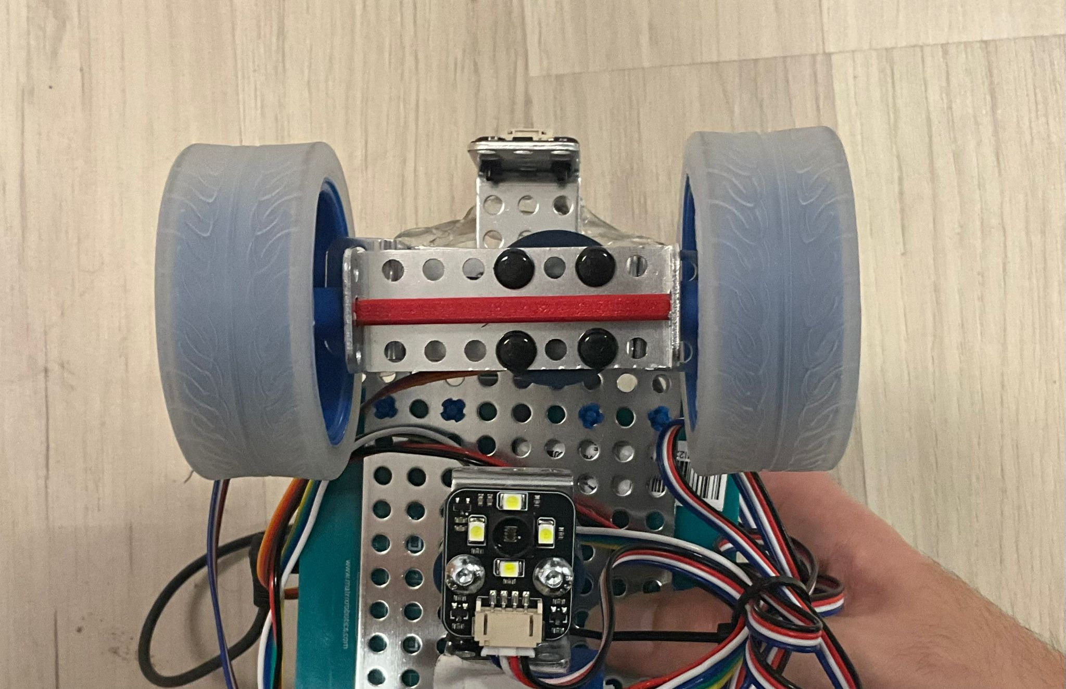
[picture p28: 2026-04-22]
v-photos/28. installed axle on robot.jpeg

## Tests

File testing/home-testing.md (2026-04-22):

# Home Testing

Because access to the official arena was limited, a custom test arena was created at home.

This made it possible to:
- repeat tests more often
- refine turning logic
- improve sensor-based navigation

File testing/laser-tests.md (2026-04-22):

# Laser Sensor Tests

The robot was upgraded to use three laser sensors.

Benefits:
- more reliable than color-based triggering
- works better at speed
- gives continuous distance feedback

The front sensor detects walls, while the side sensors help determine the best turning side.

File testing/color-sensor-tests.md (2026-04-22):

# Color Sensor Tests

The color sensor was initially used to detect blue and orange floor lines.

Problems found:
- blue was detected better than orange
- orange detection was weaker
- at higher speed, the robot could miss the line

To improve performance, HSV values were displayed on the OLED and used for calibration.

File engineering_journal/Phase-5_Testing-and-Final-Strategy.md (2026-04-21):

# Phase 5 – Testing and Final Strategy

## Testing

Due to limited access to the official arena, a custom test environment was created at home using available materials.

## Observations

* Laser sensors performed consistently
* Turning accuracy improved
* Stability improved after wheel changes

## Driving Strategies

Two strategies were developed:

### 1. Stop-before-turn

* More accurate
* Reduces drift

### 2. Continuous turning

* Faster
* Slightly less accurate

## Competition Plan

Both strategies are prepared, and the final choice will be made based on performance during competition.

## Conclusion

The robot evolved from a simple color-based system into a reliable sensor-based autonomous navigation system through testing and iterative improvements.

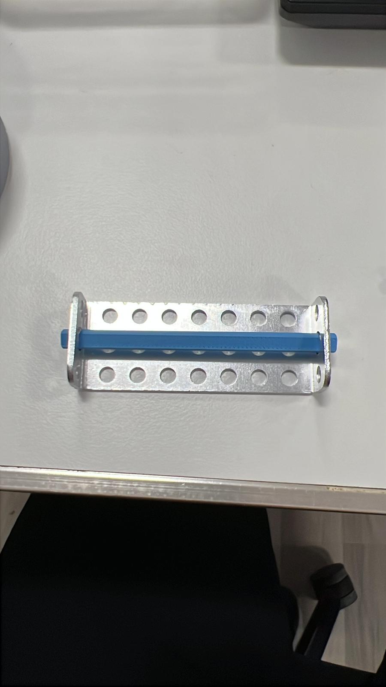
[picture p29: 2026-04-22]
v-photos/26. 3D printed axle test.jpeg

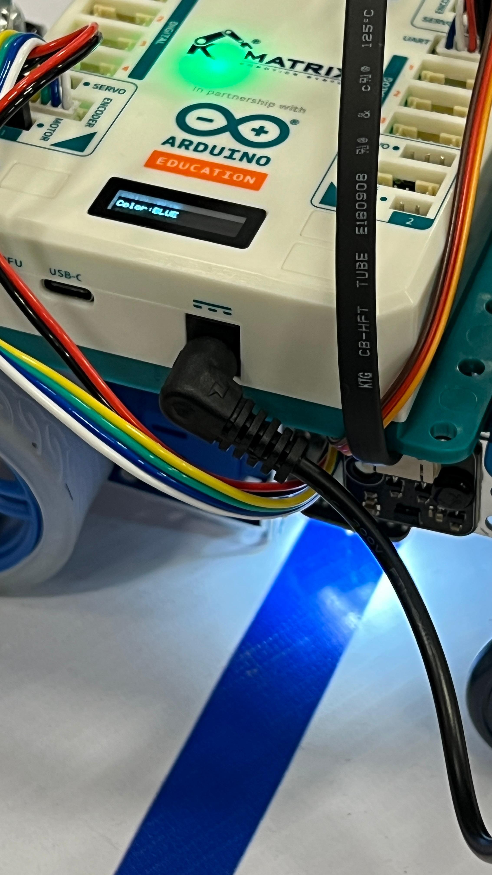
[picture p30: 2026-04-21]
v-photos/14. blue color sensor testing.jpeg

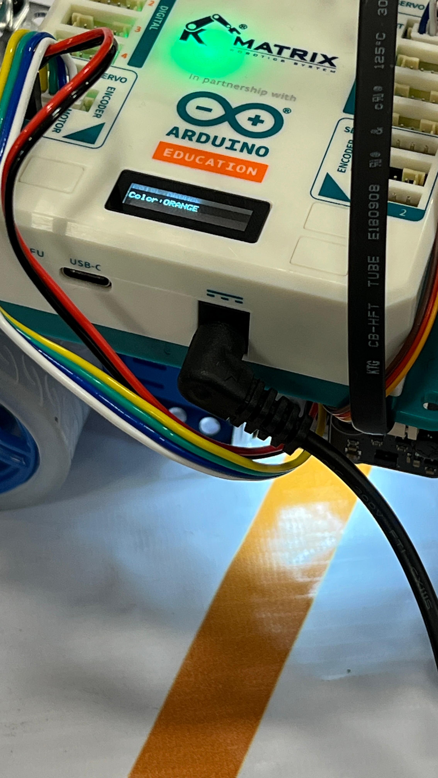
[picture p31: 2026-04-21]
v-photos/16. orange color sensor testing.jpeg

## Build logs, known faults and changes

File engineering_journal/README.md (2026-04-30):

# WRO 2026 Future Engineers - Team KCST1 Engineering Journal

## Team Information

| Name | Role |
| :--- | :--- |
| **Sara** | Hardware Design, Mechanical Integration, GitHub Management |
| **Abbas** | Software Development, Testing, System Validation |

### Coach

*   Eng. Zainab

## 1. Introduction: Blaze – Autonomous Self-Driving Robot

This Engineering Journal documents the design, development, and validation of **Blaze**, our autonomous robot developed for the **World Robot Olympiad (WRO ) 2026 – Future Engineers category**. Blaze is engineered to achieve robust, repeatable, and stable navigation within a closed arena, leveraging laser-based environmental sensing, steering-based motion control, and deterministic decision-making algorithms.

The name **Blaze** embodies speed, precision, and reliability—the foundational principles guiding our robot's design. It signifies fast and decisive movement, strong and stable performance under pressure, and consistent execution across multiple runs. Our development process involved multiple iterations, integrating mechanical improvements, sensor optimization, and refined control logic to achieve competition-level performance.

## 2. Engineering Objective

The primary objective for Blaze was to develop a robot capable of:

*   Autonomous wall detection and corner navigation.
*   Stable steering under varying speeds.
*   Consistent lap completion without external input.
*   High reliability under real competition conditions.

## 3. Mobility and Mechanical Design

This section details the design choices and mechanical considerations for the Blaze robot's chassis and drive system. Our iterative design process focused on achieving a balance between stability, maneuverability, and durability, crucial for navigating the WRO competition track.

### 3.1 Chassis Design Choices

Our chassis design prioritizes a low center of gravity and a wide wheelbase to enhance stability during high-speed maneuvers and turns. The frame is constructed from lightweight yet rigid materials to minimize overall robot weight while maximizing structural integrity.

*   **Material Selection:** High-strength aluminum profiles were chosen for the main frame due to their excellent strength-to-weight ratio and ease of assembly. This provides a robust platform that can withstand minor impacts and vibrations without compromising structural integrity.
*   **Layout:** A rectangular base with centrally mounted components (controller, battery) ensures balanced weight distribution, which is critical for consistent traction and predictable handling.
*   **Accessibility:** The design allows for easy access to internal components for maintenance, adjustments, and quick battery swaps during competition.

### 3.2 Steering and Drive Mechanism

Blaze utilizes a **differential drive system** combined with a **steering mechanism** for precise control. This hybrid approach allows for both agile turning and stable straight-line driving.

*   **Drive System:** Two TT Encoder Motors independently drive the rear wheels. The encoders provide precise feedback on wheel rotation, enabling accurate speed control and odometry for navigation.
*   **Steering Mechanism:** A single MG996R Servo Motor controls the front steering. This setup provides responsive steering input, allowing the robot to execute sharp turns and maintain its trajectory with high accuracy.

### 3.3 Torque and Speed Reasoning

The selection of motors and gear ratios was a critical aspect of our mechanical design, directly impacting the robot's performance in terms of speed, acceleration, and ability to handle varying loads.

*   **TT Encoder Motors:** These motors were chosen for their balance of torque and speed, coupled with integrated encoders for precise control. The gear ratio of the motors (e.g., 1:48) was selected to provide sufficient torque for rapid acceleration and climbing small inclines, while also allowing for a maximum speed suitable for the competition track.
    *   **Torque Calculation:** The required torque was estimated based on the robot's weight, wheel diameter, and expected acceleration. This ensured that the motors could overcome static friction and accelerate the robot effectively.
    *   **Speed Considerations:** The maximum rotational speed of the motors, combined with the wheel diameter, determined the robot's top speed. This was balanced against the need for control and stability, as excessively high speeds can lead to loss of traction and reduced accuracy.

### 3.4 Design Tradeoffs

Several design tradeoffs were considered during the development of the chassis and mechanical system:

*   **Weight vs. Durability:** A lighter robot generally achieves higher speeds and better acceleration. However, reducing weight too much can compromise durability. We opted for a balance, using lightweight materials where possible without sacrificing structural integrity.
*   **Speed vs. Precision:** As highlighted in the software architecture, there's an inherent tradeoff between speed and precision in navigation. Our mechanical design supports both strategies (Stop-Then-Turn for precision, Continuous Turn for speed) by providing a stable and responsive platform.
*   **Complexity vs. Reproducibility:** While more complex mechanical designs might offer marginal performance gains, we prioritized a design that is relatively straightforward to build and reproduce, aligning with the WRO competition's emphasis on engineering documentation and reproducibility.

### 3.5 Mechanical Innovation – Custom Axle

#### Problem:

Initial designs suffered from a loose axle, leading to unstable steering and reduced accuracy during turns. This significantly impacted the robot's ability to maintain a consistent path and achieve optimal lap times.

#### Solution:

A custom 3D printed axle was designed and implemented. This innovative solution provides a more secure and precise fit, eliminating the play in the axle and significantly improving steering stability and overall control. The CAD files for this custom axle are available in the `mechanical/CAD` directory, allowing for easy reproduction and modification.

**Result:** Precise steering and stability, leading to improved navigation and reduced error rates.

### 3.6 Testing and Iterations

Our mechanical design underwent several iterations based on testing feedback:

*   **Initial Prototype:** A basic chassis was assembled to test fundamental concepts of drive and steering. This revealed issues with axle stability, leading to the custom 3D printed axle.
*   **Wheel System Upgrade:** Early tests with mixed wheel types resulted in inconsistent tracking. Switching to a uniform MATRIX TT wheel system significantly improved stability and predictability.
*   **Stress Testing:** The chassis was subjected to various stress tests, including impacts and rapid maneuvers, to identify weak points and ensure durability. Reinforcements were added where necessary.

These iterative improvements, driven by empirical testing, were crucial in refining the mechanical design to achieve optimal performance and reliability for the competition.

## 4. Power and Sensor Architecture

This section details the power system architecture and the selection and placement of sensors, crucial for the robot's autonomous operation.

### 4.1 Component Power Consumption

The following table summarizes the estimated current draw and power consumption for the primary electrical components of the Blaze robot:

| Component | Operating Voltage (V) | Typical Current (A) | Peak Current (A) | Power Consumption (W) |
| :--- | :--- | :--- | :--- | :--- |
| MATRIX Mini R4 (Controller) | 5 | 0.2 | 0.5 | 2.5 |
| MATRIX Laser Sensor V2 (x3) | 5 | 0.05 (each) | 0.1 (each) | 0.5 (total) |
| MATRIX Color Sensor V3 | 5 | 0.02 | 0.05 | 0.25 |
| M-Vision Camera (MS-010) | 5 | 0.1 | 0.2 | 1.0 |
| TT Encoder Motor (x2) | 12 | 0.5 (each) | 1.5 (each) | 36.0 (total peak) |
| MG996R Servo Motor | 5 | 0.1 | 0.5 | 2.5 |
| **Total Estimated Peak Consumption** | | | **~4.85** | **~42.75** |

*Note: Current and power values are approximate and can vary based on specific operating conditions and load. Peak current for motors is estimated during high-load situations (e.g., rapid acceleration or turning).*

### 4.2 Power System Architecture

The robot's power system is designed around a 3-cell LiPo battery, providing a nominal voltage of 11.1V (fully charged at 12.6V). This battery feeds into a main power distribution board, which then supplies power to various components through appropriate voltage regulators:

*   **12V Line:** Directly powers the TT Encoder Motors, ensuring they receive sufficient voltage for optimal torque and speed.
*   **5V Regulator:** A dedicated 5V regulator steps down the battery voltage to supply the MATRIX Mini R4 controller, all sensors (Laser, Color, Camera), and the MG996R Servo Motor. This ensures stable and clean power for sensitive electronic components.

### 4.3 Justification of Design Choices

*   **LiPo Battery Selection:** Chosen for its high energy density and discharge rate, suitable for powering the motors and electronics for extended periods during competition rounds.
*   **Voltage Regulators:** Implemented to provide stable and correct operating voltages for each component, protecting sensitive electronics from voltage fluctuations and ensuring reliable performance.
*   **Current Draw Reasoning:** The total estimated peak current draw of approximately 4.85A (primarily driven by the motors) is well within the safe operating limits of the selected LiPo battery and voltage regulators, which are rated to handle higher continuous and peak currents. This prevents overheating and ensures consistent power delivery.

This detailed power budget analysis confirms the robustness of our power system architecture, minimizing the risk of power-related failures during critical competition moments.

### 4.4 Sensor Selection and Placement

*   **3 × MATRIX Laser Sensor V2:** These sensors are strategically placed to provide accurate distance measurements to the track walls, crucial for lane following and obstacle detection. Their reliability and independence from lighting conditions were key factors in their selection.
*   **MATRIX Color Sensor V3:** Used for initial track detection and identifying specific colored markers on the track. Its placement is optimized for detecting track lines directly beneath the robot.
*   **M-Vision Camera (MS-010):** Provides broader environmental awareness, enabling the robot to identify larger obstacles and traffic signs (pillars) for advanced decision-making. Its position is elevated to provide a wider field of view.

## 5. Software Architecture and Obstacle Strategy

This section details the software architecture and the strategies implemented for obstacle avoidance and navigation for the Blaze robot. The software is designed with modularity and flexibility in mind, allowing for easy adaptation to different challenge scenarios and continuous improvement.

### 5.1 Overall Software Architecture

The core navigation logic is implemented using a **state machine approach**, which provides a clear and structured way to manage the robot's behavior based on its current environment and mission objectives. The state machine transitions are triggered by sensor inputs and internal logic, ensuring robust and predictable operation.

### State Machine Diagram

<div align="center">
  
</div>
**Explanation of States:**

*   **Initial:** The starting state of the robot, awaiting activation.
*   **Direction Detection:** The robot determines the initial direction of travel (clockwise or counter-clockwise) based on predefined criteria or sensor readings. This decision is crucial for consistent lap completion.
*   **Continuous Turn Strategy:** If speed is prioritized, the robot enters this state, executing turns while maintaining continuous forward motion. This strategy is optimized for faster lap times.
*   **Stop-Then-Turn Strategy:** If precision is critical, the robot enters this state, coming to a complete stop before executing a turn. This ensures high accuracy and minimal overshoot.
*   **Lap Completed:** After completing the required number of laps, the robot transitions to this state.
*   **Start Parking:** The robot initiates the parking maneuver, aiming to precisely position itself in the designated parking lot.
*   **End:** The robot successfully completes its mission and enters a standby state.

### 5.2 Lane Following and Obstacle Obedience Strategy

Our primary navigation method relies on **laser-based environmental sensing** to detect walls and maintain a consistent distance from them. This approach offers superior reliability compared to color-based methods, especially under varying lighting conditions.

### Lane Following Algorithm

Our lane following algorithm utilizes a **proportional controller** based on the lateral offset of the detected lane center. The laser sensors provide continuous feedback on the robot's distance to the left and right walls. This information is used to calculate the robot's deviation from the center of the lane. A proportional control loop then adjusts the steering angle to minimize this deviation, keeping the robot centered within the lane.

*   **Input:** Distance readings from left and right laser sensors.
*   **Calculation:** `Error = Distance_Right - Distance_Left`
*   **Output:** Steering adjustment proportional to `Error`.

### Obstacle Obedience Strategy

For the Obstacle Challenge, the robot must interpret traffic signs (green and red pillars) and adjust its lane-following behavior accordingly. Our strategy incorporates the following logic:

*   **Green Pillar (Keep Left):** Upon detecting a green pillar, the robot temporarily adjusts its proportional control to favor the left side of the lane, maintaining a closer distance to the left wall while passing the obstacle.
*   **Red Pillar (Keep Right):** Similarly, upon detecting a red pillar, the robot adjusts its control to favor the right side of the lane, maintaining a closer distance to the right wall.
*   **Avoidance:** The laser sensors also provide data for obstacle avoidance. If an obstacle is detected directly in the robot's path, a pre-programmed avoidance maneuver is initiated, which may involve temporary deviation from the lane center, followed by a return to the lane once the obstacle is cleared.

### 5.3 Algorithms Used

*   **Proportional Control (P-Controller):** Used for lane following to maintain the robot's position relative to the lane center. The steering output is directly proportional to the error (deviation from center).
*   **State Machine Logic:** Manages the overall flow of the robot's behavior, transitioning between different operational states (e.g., direction detection, continuous turn, stop-then-turn, parking) based on sensor inputs and mission progress.
*   **Decision-Making Algorithms:** Simple conditional logic is used for obstacle obedience (green/red pillars) and for selecting between continuous turn and stop-then-turn strategies based on predefined criteria or real-time performance metrics.

### 5.4 Testing and Tuning Process

Our software was developed through an iterative process of testing and tuning, primarily conducted on a custom home arena that replicated competition conditions.

*   **Unit Testing:** Individual modules, such as sensor reading, motor control, and basic navigation functions, were tested independently to ensure their correct operation.
*   **Integration Testing:** Different software components were integrated and tested together to verify their interactions and overall system behavior.
*   **Performance Tuning:** Parameters for the proportional controller (e.g., proportional gain) were fine-tuned through extensive experimentation on the test track. Metrics such as lap consistency, speed, and accuracy of turns were used to evaluate performance.
*   **Edge Case Handling:** The robot was tested under various challenging scenarios, including tight corners, unexpected obstacles, and different lighting conditions, to identify and address potential failure modes.

This rigorous testing and tuning process allowed us to optimize the robot's performance, ensuring its stability, reliability, and ability to consistently complete the challenges.

## 6. Systems Thinking and Engineering Decisions

Our development process for Blaze was guided by a strong emphasis on systems thinking, where the robot is viewed as an integrated system rather than a collection of independent parts. This approach allowed us to make informed engineering decisions, considering the interplay between different subsystems and their impact on overall performance.

### 6.1 Subsystem Interactions

*   **Mobility & Software:** The mechanical design of the chassis and drive system directly influences the effectiveness of the software's navigation algorithms. For instance, a stable chassis and precise steering mechanism enable the proportional controller to make accurate adjustments, leading to smoother lane following.
*   **Sensors & Software:** The choice and placement of sensors dictate the quality and type of data available to the software. Laser sensors provide reliable distance data, which is crucial for the software's ability to accurately detect walls and obstacles.
*   **Power & All Subsystems:** The power system architecture ensures that all components receive stable and sufficient power, preventing unexpected behavior or failures due to power fluctuations. A well-designed power budget is critical for sustained operation.

### 6.2 Engineering Reasoning Behind Decisions

Throughout the project, decisions were made based on a careful evaluation of tradeoffs and constraints.

*   **Sensor Selection:** The decision to transition from color-based navigation to laser-based sensing was driven by the need for greater reliability and consistency under varying lighting conditions. While color sensors might be simpler to implement initially, their performance was found to be too sensitive to environmental factors. Laser sensors, although potentially more complex to integrate, provided the robust distance measurements required for accurate wall detection and lane following.
*   **Steering Mechanism:** The choice of a differential drive system combined with a steering mechanism was a deliberate tradeoff between agility and stability. This hybrid approach allows for both sharp turns and stable straight-line driving, providing a versatile platform for navigating the competition track.
*   **Custom Axle:** The development of a custom 3D printed axle was a direct response to the instability observed in the initial steering mechanism. This decision highlights our commitment to addressing mechanical issues through innovative design solutions, rather than relying solely on software compensation.

### 6.3 Constraints and Tradeoffs

*   **Weight vs. Durability:** A lighter robot generally achieves higher speeds and better acceleration. However, reducing weight too much can compromise durability. We opted for a balance, using lightweight materials where possible without sacrificing structural integrity.
*   **Speed vs. Precision:** As highlighted in the software architecture, there's an inherent tradeoff between speed and precision in navigation. Our mechanical design supports both strategies (Stop-Then-Turn for precision, Continuous Turn for speed) by providing a stable and responsive platform.
*   **Complexity vs. Reproducibility:** While more complex mechanical designs might offer marginal performance gains, we prioritized a design that is relatively straightforward to build and reproduce, aligning with the WRO competition's emphasis on engineering documentation and reproducibility.

### 6.4 Iteration and Testing Cycles

Our development process was characterized by continuous iteration and testing.

*   **Initial Prototype:** A basic chassis was assembled to test fundamental concepts of drive and steering. This revealed issues with axle stability, leading to the custom 3D printed axle.
*   **Wheel System Upgrade:** Early tests with mixed wheel types resulted in inconsistent tracking. Switching to a uniform MATRIX TT wheel system significantly improved stability and predictability.
*   **Stress Testing:** The chassis was subjected to various stress tests, including impacts and rapid maneuvers, to identify weak points and ensure durability. Reinforcements were added where necessary.

### 6.5 Risk Identification and Mitigation Actions

*   **Power Failure:** The risk of power failure during a competition round was mitigated by implementing a robust power system architecture with a dedicated 5V regulator for sensitive electronics and a 12V line for the motors. A detailed power budget analysis confirmed the adequacy of the selected LiPo battery and voltage regulators.
*   **Sensor Interference:** The risk of sensor interference or misreadings was addressed by carefully selecting and placing the sensors. Laser sensors were chosen for their reliability and independence from lighting conditions, while the camera was positioned to provide a clear view of the track and obstacles.
*   **Mechanical Instability:** The risk of mechanical instability, particularly in the steering mechanism, was mitigated by designing and implementing a custom 3D printed axle. This innovative solution provided a more secure and precise fit, eliminating play and significantly improving steering stability.

## 7. Reproducibility and GitHub Quality

This section details the structure and quality of our GitHub repository, ensuring that our engineering process and final robot design are fully reproducible by other teams.

### 7.1 GitHub Structure and Clarity

Our GitHub repository is organized logically, with clear directories for different aspects of the project:

*   `engineering_journal/`: Detailed documentation of the engineering process, design decisions, and iterative improvements.
*   `hardware/`: Specifications and documentation for all electronic components, including the crucial power budget.
*   `mechanical/`: Mechanical design files, including CAD models for 3D printed parts and assembly instructions.
*   `schemes/`: Wiring diagrams and system block diagrams.
*   `software/`: Documentation of software architecture and algorithms, including a state machine diagram.
*   `src/`: All source code files for the robot.
*   `testing/`: Documentation of testing procedures, results, and validation reports.
*   `t-photos/`: Team photos.
*   `v-photos/`: Photos of the vehicle from various angles.
*   `video/`: Links to demonstration videos.

### 7.2 Commit History

Our repository features a comprehensive commit history, reflecting the iterative nature of our development process. The commits are meaningful and provide a clear record of the changes made over time.

### 7.3 README Content and Structure

The main `README.md` file provides a comprehensive overview of the project, including team information, engineering objectives, hardware and software architecture, and instructions for building and compiling the code. It serves as a central hub for understanding the project and navigating the repository.

### 7.4 File Organization

Files are organized logically within their respective directories, making it easy to locate specific information or components. The use of clear and descriptive filenames further enhances the repository's usability.

### 7.5 CAD, Code, Wiring, and Related Technical Files

All necessary technical files, including CAD models, source code, and wiring diagrams, are included in the repository. This ensures that other teams have access to all the information required to reproduce our robot design.

### 7.6 Reproducibility of the Robot

Our comprehensive documentation, clear repository structure, and inclusion of all necessary technical files ensure that our robot design is fully reproducible. Other teams can follow our engineering process, understand our design decisions, and build their own version of Blaze using the provided resources.

## 8. Conclusion

The development of Blaze has been a challenging yet rewarding engineering journey. Through a systematic approach, rigorous testing, and continuous iteration, we have created a robust and reliable autonomous robot capable of navigating the WRO 2026 Future Engineers competition track. This Engineering Journal serves as a comprehensive record of our work, demonstrating our commitment to engineering excellence and our willingness to share our knowledge with the broader robotics community.

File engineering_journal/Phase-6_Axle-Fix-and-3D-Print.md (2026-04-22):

# Phase 6: Axle Fix and 3D Printed Solution

## Problem Identified
During testing, the front wheel axle connected to the steering servo was not fitting tightly inside the wheels.

This caused:
- unstable steering behavior
- shaking and vibration in the front wheels
- inconsistent turning accuracy

The looseness between the axle and the wheel reduced the overall control of the robot, especially during turns.

---

## Attempted Solutions
Initially, we considered:
- applying glue to secure the axle
- adjusting the existing axle manually

However, these solutions were not reliable or precise enough.

---

## Final Solution: 3D Printed Axle

We designed and produced a custom 3D printed axle that fits perfectly inside the wheel.

### Improvements achieved:
- tight and stable connection between axle and wheel
- elimination of unwanted movement
- improved steering precision
- more consistent robot behavior during turns

---

## Implementation
The new axle was installed in the front wheel steering system.

The design ensured:
- correct alignment with the servo
- proper fit inside the wheel hub
- durability during movement

---

## Result
After installing the 3D printed axle:
- the steering became more stable
- wheel shaking was eliminated
- turning accuracy improved significantly

This modification directly improved the robot's performance in navigation tasks.

---

## Conclusion
This improvement shows the importance of mechanical precision in robot design.

By identifying the issue and developing a custom 3D printed solution, we were able to significantly enhance the robot’s reliability and control.

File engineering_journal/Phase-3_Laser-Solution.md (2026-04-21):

# Phase 3 – Laser Sensor Solution

## Solution

The system was redesigned using three laser sensors:

* Front sensor → detects walls
* Left sensor → measures left distance
* Right sensor → measures right distance

## Logic

1. Detect wall ahead
2. Compare left and right distances
3. Turn toward the side with more space

## Advantage

* Works regardless of floor color
* More reliable at high speeds
* Better decision making

## Result

Navigation became significantly more consistent and stable.

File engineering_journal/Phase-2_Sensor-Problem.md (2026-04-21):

# Phase 2 – Sensor Limitation Problem

## Problem

During testing, the robot occasionally missed the colored lines due to speed and sensor delay.

## Impact

* Missed turns
* Inconsistent navigation
* Reduced reliability

## Analysis

The issue was caused by:

* Limited detection time window
* Fast robot movement
* Sensor accuracy limitations

## Decision

A more reliable sensing system was required.

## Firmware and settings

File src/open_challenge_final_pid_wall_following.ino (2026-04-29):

#include "MatrixMiniR4.h"

/*
  =====================================================
  WRO Future Engineers 2026 - Open Challenge Final Code
  Robot Name: Blaze
  Board: MATRIX Mini R4

  Strategy:
  - Robot starts only when DOWN button is pressed.
  - Default direction is clockwise (CW).
  - UP button before start toggles between CW and CCW.
  - CW mode follows the LEFT wall.
  - CCW mode follows the RIGHT wall.
  - Laser sensors are used for wall following and front wall avoidance.
  - Color sensor detects BLUE markers for lap/turn counting.
  - OLED is only used before start, then cleared for faster performance.

  Main control methods:
  - Single-wall PID following for smooth driving.
  - Timed front-wall steering override for corners.
  - Smooth servo movement to reduce sudden steering changes.
  =====================================================
*/

// =====================================================
// START / RUN STATE
// =====================================================

// false = waiting for start button
// true  = robot is running
bool started = false;

// false = robot still running
// true  = run completed
bool finished = false;

// true  = clockwise mode
// false = counter-clockwise mode
bool clockwiseMode = true;


// =====================================================
// MOTOR TUNING
// =====================================================

// Normal straight driving speed
int speedStraight = 82;

// Speed used during corner/front-wall avoidance
int speedCorner = 68;

// Minimum allowed motor speed
int speedMin = 75;

// Maximum allowed motor speed
int speedMax = 90;

// Stores the current motor power after clamping
int motorPower = 0;


// =====================================================
// SERVO TUNING
// =====================================================

// Servo center angle: wheels straight
int servoCenter = 92;

// Maximum left steering limit
int servoLeftLimit = 124;

// Maximum right steering limit
int servoRightLimit = 60;

// Current servo position used for smoothing
float servoNow = 92.0f;

// Target servo position calculated by PID or front-wall override
float servoTarget = 92.0f;

// Smooth factor controls how gradually the servo moves toward the target
float servoSmoothFactor = 0.18f;

// Maximum servo movement step per update
float maxServoStep = 5.5f;


// =====================================================
// PID TUNING
// =====================================================

// Proportional gain: reacts to current wall distance error
float Kp = 0.28f;

// Integral gain: corrects small long-term error
float Ki = 0.0004f;

// Derivative gain: reduces overshoot by reacting to error change
float Kd = 0.75f;

// Current wall distance error
float error = 0.0f;

// Previous loop error
float prevError = 0.0f;

// Accumulated error
float integral = 0.0f;

// Rate of change of error
float derivative = 0.0f;

// Final PID output used to adjust servo angle
float pid = 0.0f;

// Wall distance target for clockwise mode
// In CW mode, the robot follows the LEFT wall
int targetWallDistCW = 550;

// Wall distance target for counter-clockwise mode
// In CCW mode, the robot follows the RIGHT wall
int targetWallDistCCW = 700;


// =====================================================
// SENSOR VALUES
// =====================================================

// Front laser sensor reading
int frontS = 0;

// Right laser sensor reading
int rightS = 0;

// Left laser sensor reading
int leftS = 0;


// =====================================================
// FRONT WALL AVOIDANCE THRESHOLDS
// =====================================================

// Front wall detection starts below this value
int frontAvoidStart = 2750;

// Stronger avoidance below this value
int frontAvoidHard = 2000;

// Panic/very-close avoidance below this value
int frontAvoidPanic = 1500;


// =====================================================
// TIMED FRONT TURN STATE
// =====================================================

// true while robot is performing a timed corner turn
bool frontTurnActive = false;

// Time when timed front turn should end
unsigned long frontTurnEndMs = 0;

// Servo target during front-wall avoidance
float frontTurnServoTarget = 92.0f;

// Motor speed during front-wall avoidance
int frontTurnSpeed = 0;

// Timed front turn duration for CW mode
const unsigned long frontTurnDurationMsCW = 600;

// Timed front turn duration for CCW mode
const unsigned long frontTurnDurationMsCCW = 850;


// =====================================================
// VALID SENSOR RANGE
// =====================================================

// Minimum valid laser reading
int validMin = 20;

// Maximum valid laser reading
int validMax = 3000;


// =====================================================
// TIMING
// =====================================================

// Stores last time control loop was executed
unsigned long lastControlMs = 0;

// Control loop period in milliseconds
// 10 ms = fast response
const unsigned long controlPeriodMs = 10;


// =====================================================
// BUTTON DEBOUNCE
// =====================================================

// Stores last button press time
unsigned long lastBtnMs = 0;

// Prevents repeated button triggers
const unsigned long btnDebounceMs = 180;


// =====================================================
// LAP COUNTING USING BLUE LINE
// =====================================================

// Number of detected blue markers
int TURNS = 0;

// Number of required blue detections before stopping
const int REQUIRED_BLUE_DETECTIONS = 12;

// Stores previous color detection state
bool lapColorPrev = false;

// Last time a blue marker was counted
unsigned long lastLapMs = 0;

// Minimum time between blue detections
// Prevents counting the same line multiple times
const unsigned long lapCooldownMs = 2000;


// =====================================================
// FLOOR COLOR ENUM
// =====================================================

enum FloorColor
{
  FLOOR_UNKNOWN = 0,
  FLOOR_BLUE
};


// =====================================================
// HELPER FUNCTIONS
// =====================================================

// Clamps an integer between minimum and maximum values
int clampInt(int v, int mn, int mx)
{
  if (v < mn) return mn;
  if (v > mx) return mx;
  return v;
}

// Clamps a float between minimum and maximum values
float clampFloat(float v, float mn, float mx)
{
  if (v < mn) return mn;
  if (v > mx) return mx;
  return v;
}


// =====================================================
// FAST SENSOR READ FUNCTIONS
// =====================================================

// Read front laser sensor
int readFrontFast()
{
  return MiniR4.I2C2.MXLaserV2.getDistance();
}

// Read right laser sensor
int readRightFast()
{
  return MiniR4.I2C3.MXLaserV2.getDistance();
}

// Read left laser sensor
int readLeftFast()
{
  return MiniR4.I2C4.MXLaserV2.getDistance();
}

// Checks whether laser reading is within valid range
bool validDist(int d)
{
  return (d >= validMin && d <= validMax);
}


// =====================================================
// BLUE FLOOR COLOR DETECTION
// =====================================================

// Reads RGB values from color sensor and detects blue only
FloorColor readFloorColorForLap()
{
  int r = MiniR4.I2C1.MXColorV3.getR();
  int g = MiniR4.I2C1.MXColorV3.getG();
  int b = MiniR4.I2C1.MXColorV3.getB();

  // Reject neutral/white floor by checking if RGB values are too similar
  int rgDiff = abs(r - g);
  int rbDiff = abs(r - b);
  int gbDiff = abs(g - b);

  if (rgDiff < 18 && rbDiff < 18 && gbDiff < 18)
  {
    return FLOOR_UNKNOWN;
  }

  // Detect blue when blue value is strong and greater than red and green
  if (b > 100 && b > r && b > g)
  {
    return FLOOR_BLUE;
  }

  return FLOOR_UNKNOWN;
}


// =====================================================
// MOTOR AND SERVO CONTROL
// =====================================================

// Sets motor power after limiting it between -100 and 100
void setMotor(int pwr)
{
  motorPower = clampInt(pwr, -100, 100);
  MiniR4.M1.setPower(motorPower);
}

// Immediately sets servo angle within safe steering limits
void setServoImmediate(int angle)
{
  angle = clampInt(angle, servoRightLimit, servoLeftLimit);
  MiniR4.RC3.setAngle(angle);
}

// Smoothly moves servo toward target angle
// This avoids sudden steering movements and improves stability
void updateServoSmooth()
{
  float diff = servoTarget - servoNow;

  // Limit maximum servo step
  if (diff > maxServoStep) diff = maxServoStep;
  if (diff < -maxServoStep) diff = -maxServoStep;

  // Move servo gradually toward target
  servoNow += diff;
  servoNow += (servoTarget - servoNow) * servoSmoothFactor;

  // Keep servo within safe range
  servoNow = clampFloat(servoNow, (float)servoRightLimit, (float)servoLeftLimit);

  // Send final angle to servo
  MiniR4.RC3.setAngle((int)(servoNow + 0.5f));
}

// Stops motor and centers steering
void stopRobot()
{
  setMotor(0);
  servoTarget = servoCenter;
  servoNow = servoCenter;
  setServoImmediate(servoCenter);
}

// Resets PID values and front turn state before starting run
void resetController()
{
  error = 0.0f;
  prevError = 0.0f;
  integral = 0.0f;
  derivative = 0.0f;
  pid = 0.0f;

  servoNow = (float)servoCenter;
  servoTarget = (float)servoCenter;

  frontTurnActive = false;
  frontTurnEndMs = 0;
}


// =====================================================
// OLED DISPLAY BEFORE START
// =====================================================

// Displays direction selection screen before run starts
void drawStandby()
{
  MiniR4.OLED.clearDisplay();

  MiniR4.OLED.setCursor(0, 0);
  MiniR4.OLED.print("Open Challenge");

  MiniR4.OLED.setCursor(0, 10);
  MiniR4.OLED.print("UP: Toggle Dir");

  MiniR4.OLED.setCursor(0, 20);
  MiniR4.OLED.print("DOWN: Start ");
  MiniR4.OLED.print(clockwiseMode ? "CW" : "CCW");

  MiniR4.OLED.display();
}


// =====================================================
// FINISH RUN
// =====================================================

// Stops the robot after required blue detections
void finishRun()
{
  delay(1250);
  finished = true;
  stopRobot();

  // Keep robot stopped forever
  while (true) {}
}


// =====================================================
// SETUP
// =====================================================

void setup()
{
  // Initialize MATRIX Mini R4
  MiniR4.begin();

  // Set battery type to 2-cell
  MiniR4.PWR.setBattCell(2);

  // Motor setup
  MiniR4.M1.setReverse(false);
  MiniR4.M1.setPower(0);
  MiniR4.M1.setBrake(false);
  MiniR4.M1.resetCounter();

  // Center servo at startup
  setServoImmediate(servoCenter);

  // Initialize sensors
  MiniR4.I2C1.MXColorV3.begin();   // Color sensor
  MiniR4.I2C2.MXLaserV2.begin();   // Front laser sensor
  MiniR4.I2C3.MXLaserV2.begin();   // Right laser sensor
  MiniR4.I2C4.MXLaserV2.begin();   // Left laser sensor

  // Show standby screen
  drawStandby();
}


// =====================================================
// MAIN LOOP
// =====================================================

void loop()
{
  // Stop updating if run is already finished
  if (finished)
  {
    return;
  }

  // =====================================================
  // PRE-START MODE SELECTION
  // =====================================================

  if (!started)
  {
    unsigned long now = millis();

    // UP button toggles between CW and CCW before starting
    if (MiniR4.BTN_UP.getState() && (now - lastBtnMs > btnDebounceMs))
    {
      clockwiseMode = !clockwiseMode;
      lastBtnMs = now;
      drawStandby();
    }

    // DOWN button starts the run
    if (MiniR4.BTN_DOWN.getState() && (now - lastBtnMs > btnDebounceMs))
    {
      started = true;

      resetController();

      lastControlMs = millis();
      lastLapMs = millis();
      lastBtnMs = now;

      // Clear OLED after start to reduce display update load
      MiniR4.OLED.clearDisplay();
      MiniR4.OLED.display();

      delay(80);
    }
    else
    {
      return;
    }
  }

  // CW mode follows left wall
  // CCW mode follows right wall
  bool followRightWall = !clockwiseMode;

  // Select wall target based on direction
  int activeTargetWallDist = clockwiseMode ? targetWallDistCW : targetWallDistCCW;

  // Select front turn duration based on direction
  unsigned long activeFrontTurnDurationMs =
    clockwiseMode ? frontTurnDurationMsCW : frontTurnDurationMsCCW;

  // =====================================================
  // CONTROL LOOP TIMING
  // =====================================================

  unsigned long nowMs = millis();

  // Run main control logic every 10 ms
  // If not time yet, only update servo smoothing
  if (nowMs - lastControlMs < controlPeriodMs)
  {
    updateServoSmooth();
    return;
  }

  float dt = (nowMs - lastControlMs) / 1000.0f;
  lastControlMs = nowMs;

  if (dt <= 0.0f)
  {
    dt = 0.01f;
  }

  // =====================================================
  // READ SENSORS
  // =====================================================

  frontS = readFrontFast();
  rightS = readRightFast();
  leftS  = readLeftFast();

  bool frontValid = validDist(frontS);
  bool rightValid = validDist(rightS);
  bool leftValid  = validDist(leftS);

  // =====================================================
  // TIMED FRONT TURN STATE
  // =====================================================

  // End timed front turn after its duration expires
  if (frontTurnActive && nowMs >= frontTurnEndMs)
  {
    frontTurnActive = false;
  }

  // =====================================================
  // FRONT WALL AVOIDANCE OVERRIDE
  // =====================================================

  if (frontTurnActive)
  {
    // Continue the timed corner steering action
    servoTarget = frontTurnServoTarget;
    servoTarget = clampFloat(servoTarget, (float)servoRightLimit, (float)servoLeftLimit);

    int desiredSpeed = clampInt(frontTurnSpeed, speedMin, speedMax);
    setMotor(desiredSpeed);

    // Temporarily make servo respond faster during cornering
    float savedSmooth = servoSmoothFactor;
    float savedStep = maxServoStep;

    servoSmoothFactor = 0.35f;
    maxServoStep = 10.0f;

    updateServoSmooth();

    servoSmoothFactor = savedSmooth;
    maxServoStep = savedStep;
  }
  else if (frontValid && frontS < frontAvoidStart)
  {
    // Front wall detected, start corner avoidance

    float k;

    // Closer front wall = stronger steering correction
    if (frontS < frontAvoidPanic)
    {
      k = 360.0f;
    }
    else if (frontS < frontAvoidHard)
    {
      k = 260.0f;
    }
    else
    {
      k = 150.0f;
    }

    // CCW follows right wall, so front avoidance turns left
    // CW follows left wall, so front avoidance turns right
    if (followRightWall)
    {
      frontTurnServoTarget = (float)servoCenter + k;  // turn left
    }
    else
    {
      frontTurnServoTarget = (float)servoCenter - k;  // turn right
    }

    frontTurnServoTarget =
      clampFloat(frontTurnServoTarget, (float)servoRightLimit, (float)servoLeftLimit);

    // Reduce speed when approaching front wall
    int desiredSpeed = speedCorner;

    if (frontS < frontAvoidHard)
    {
      desiredSpeed = speedMin;
    }

    if (frontS < frontAvoidPanic)
    {
      desiredSpeed = speedMin - 5;
    }

    frontTurnSpeed = clampInt(desiredSpeed, speedMin, speedMax);

    // Activate timed front turn
    frontTurnActive = true;
    frontTurnEndMs = nowMs + activeFrontTurnDurationMs;

    servoTarget = frontTurnServoTarget;
    setMotor(frontTurnSpeed);

    // Temporarily increase servo response during corner entry
    float savedSmooth = servoSmoothFactor;
    float savedStep = maxServoStep;

    servoSmoothFactor = 0.35f;
    maxServoStep = 10.0f;

    updateServoSmooth();

    servoSmoothFactor = savedSmooth;
    maxServoStep = savedStep;
  }
  else
  {
    // =====================================================
    // NORMAL SINGLE-WALL PID FOLLOWING
    // =====================================================

    if (followRightWall)
    {
      // CCW mode: follow right wall
      if (rightValid)
      {
        error = (float)(activeTargetWallDist - rightS);
      }
      else if (leftValid)
      {
        // fallback if right sensor reading is invalid
        error = (float)(leftS - activeTargetWallDist);
      }
      else
      {
        // if both side readings are invalid, slowly decay previous error
        error = prevError * 0.7f;
      }
    }
    else
    {
      // CW mode: follow left wall
      if (leftValid)
      {
        error = (float)(leftS - activeTargetWallDist);
      }
      else if (rightValid)
      {
        // fallback if left sensor reading is invalid
        error = (float)(activeTargetWallDist - rightS);
      }
      else
      {
        // if both side readings are invalid, slowly decay previous error
        error = prevError * 0.7f;
      }
    }

    // Only accumulate integral for reasonable error values
    // This prevents integral windup from large bad readings
    if (error > -300.0f && error < 300.0f)
    {
      integral += error * dt;
    }

    integral = clampFloat(integral, -250.0f, 250.0f);

    // Calculate derivative and PID output
    derivative = (error - prevError) / dt;
    pid = Kp * error + Ki * integral + Kd * derivative;
    prevError = error;

    // Convert PID output into servo target
    servoTarget = (float)servoCenter + pid;
    servoTarget = clampFloat(servoTarget, (float)servoRightLimit, (float)servoLeftLimit);

    // Reduce speed if steering angle is large
    int desiredSpeed = speedStraight;
    int steerAmount = abs((int)(servoTarget - servoCenter));

    if (steerAmount > 18) desiredSpeed -= 5;
    if (steerAmount > 28) desiredSpeed -= 6;
    if (steerAmount > 36) desiredSpeed -= 6;

    desiredSpeed = clampInt(desiredSpeed, speedMin, speedMax);

    setMotor(desiredSpeed);
    updateServoSmooth();
  }

  // =====================================================
  // LAP COUNTING USING BLUE COLOR
  // =====================================================

  FloorColor floorNow = readFloorColorForLap();
  bool blueNow = (floorNow == FLOOR_BLUE);

  // Count only the rising edge of blue detection
  if (blueNow && !lapColorPrev)
  {
    if (millis() - lastLapMs > lapCooldownMs)
    {
      TURNS++;
      lastLapMs = millis();
    }
  }

  lapColorPrev = blueNow;

  // Stop robot after required number of blue detections
  if (TURNS >= REQUIRED_BLUE_DETECTIONS)
  {
    finishRun();
  }
}

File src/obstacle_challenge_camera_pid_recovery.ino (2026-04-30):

#include "MatrixMiniR4.h"

// =====================================================
// WRO FE Obstacle Challenge - Robust + Reverse Recovery
// Matrix Mini R4
//
// Camera packet expected (Serial1):
// seen,color,cx,cy,w,h,score,zone
// color: 1=RED, 2=GREEN
//
// Priority:
// 1) Reverse recovery (safety + reposition)
// 2) Camera obstacle passing (RED pass-right, GREEN pass-left)
// 3) Front wall obstacle-aware assist
// 4) Normal side-wall PID
// =====================================================

// ---------------- Run state ----------------
bool started = false;
bool finished = false;
bool clockwiseMode = true; // true=CW, false=CCW

// ---------------- Motor tuning ----------------
int speedStraight = 52;
int speedCorner   = 44;
int speedMin      = 36;
int speedMax      = 58;

// Reverse power (negative)
int reverseLightPower = -30;
int reverseHardPower  = -42;

// ---------------- Servo tuning ----------------
int servoCenter = 92;
int servoLeftLimit  = 124;   // larger angle => LEFT
int servoRightLimit = 60;    // smaller angle => RIGHT

float servoNow = 92.0f;
float servoTarget = 92.0f;
float servoSmoothFactor = 0.24f;
float maxServoStep = 6.0f;

// ---------------- PID tuning ----------------
float Kp = 0.23f;
float Ki = 0.00025f;
float Kd = 0.40f;

float error = 0.0f;
float prevError = 0.0f;
float integral = 0.0f;
float derivative = 0.0f;
float pid = 0.0f;

// Per-direction wall target
int targetWallDistCW  = 620;
int targetWallDistCCW = 640;

// ---------------- Distance sensors ----------------
int frontS = 0;
int rightS = 0;
int leftS  = 0;

// Filtered side distance
float rightFilt = 0.0f;
float leftFilt  = 0.0f;
bool sideFilterInit = false;
const float sideFilterAlpha = 0.35f;

// Valid ranges
int validMin = 20;
int validMax = 3000;

// Front thresholds
int frontAvoidStart = 3000;
int frontAvoidHard  = 2350;
int frontAvoidPanic = 1800;

// ---------------- Reverse recovery ----------------
bool reverseActive = false;
unsigned long reverseEndMs = 0;
int reversePowerCmd = 0;
float reverseServoTarget = 92.0f;

// Reverse timing
const unsigned long reverseLightMs = 180;
const unsigned long reverseHardMs  = 300;
const unsigned long reverseCooldownMs = 220;
unsigned long reverseCooldownUntilMs = 0;

// ---------------- Front timed assist ----------------
bool frontTurnActive = false;
unsigned long frontTurnEndMs = 0;
float frontTurnServoTarget = 92.0f;
int frontTurnSpeed = 0;
const unsigned long frontTurnDurationMsCW  = 700;
const unsigned long frontTurnDurationMsCCW = 860;

// ---------------- Camera packet ----------------
// seen,color,cx,cy,w,h,score,zone
int CamData[10];
String camLine = "";
unsigned long lastValidCameraPacketMs = 0;
const unsigned long cameraTimeoutMs = 220;

const int CAM_NONE  = 0;
const int CAM_RED   = 1;
const int CAM_GREEN = 2;

const int minCameraScore = 180;
const int minCameraHeight = 20;
const int minCameraWidth  = 6;

// Obstacle lock/guidance
bool obstacleLocked = false;
int lockedColor = CAM_NONE;
unsigned long lastObstacleSeenMs = 0;
const unsigned long obstacleLostTimeoutMs = 260;

bool obstacleGuideActive = false;
unsigned long obstacleGuideUntilMs = 0;
const unsigned long obstacleGuideHoldMs = 160;

float obstacleServoTarget = 92.0f;
int obstacleSpeed = 0;
int lastObstacleSteerCmd = 0; // -2..+2

// Pass-side targets in camera image
const int targetCxRed   = 88;   // RED pass-right => keep obstacle left in image
const int targetCxGreen = 232;  // GREEN pass-left => keep obstacle right in image
const int cxDeadband = 12;
const int cxStrongBand = 44;

// ---------------- Timing ----------------
unsigned long lastControlMs = 0;
const unsigned long controlPeriodMs = 12;

unsigned long lastBtnMs = 0;
const unsigned long btnDebounceMs = 180;

// ---------------- Lap count (BLUE only) ----------------
int TURNS = 0;
const int REQUIRED_BLUE_DETECTIONS = 12;
bool lapColorPrev = false;
unsigned long lastLapMs = 0;
const unsigned long lapCooldownMs = 2200;

enum FloorColor {
  FLOOR_UNKNOWN = 0,
  FLOOR_BLUE
};

// =====================================================
// Utilities
// =====================================================
int clampInt(int v, int mn, int mx)
{
  if (v < mn) return mn;
  if (v > mx) return mx;
  return v;
}

float clampFloat(float v, float mn, float mx)
{
  if (v < mn) return mn;
  if (v > mx) return mx;
  return v;
}

bool validDist(int d)
{
  return (d >= validMin && d <= validMax);
}

int readFrontFast() { return MiniR4.I2C2.MXLaserV2.getDistance(); }
int readRightFast() { return MiniR4.I2C3.MXLaserV2.getDistance(); }
int readLeftFast()  { return MiniR4.I2C4.MXLaserV2.getDistance(); }

void setMotor(int pwr)
{
  MiniR4.M1.setPower(clampInt(pwr, -100, 100));
}

void setServoImmediate(int angle)
{
  angle = clampInt(angle, servoRightLimit, servoLeftLimit);
  MiniR4.RC3.setAngle(angle);
}

void updateServoSmooth()
{
  float diff = servoTarget - servoNow;
  if (diff > maxServoStep) diff = maxServoStep;
  if (diff < -maxServoStep) diff = -maxServoStep;

  servoNow += diff;
  servoNow += (servoTarget - servoNow) * servoSmoothFactor;
  servoNow = clampFloat(servoNow, (float)servoRightLimit, (float)servoLeftLimit);

  MiniR4.RC3.setAngle((int)(servoNow + 0.5f));
}

void stopRobot()
{
  setMotor(0);
  servoTarget = (float)servoCenter;
  servoNow = (float)servoCenter;
  setServoImmediate(servoCenter);
}

void resetController()
{
  error = 0.0f;
  prevError = 0.0f;
  integral = 0.0f;
  derivative = 0.0f;
  pid = 0.0f;

  servoTarget = (float)servoCenter;
  servoNow = (float)servoCenter;

  frontTurnActive = false;
  obstacleGuideActive = false;
  obstacleLocked = false;
  lockedColor = CAM_NONE;
  reverseActive = false;
  reverseCooldownUntilMs = 0;
  lastObstacleSteerCmd = 0;

  sideFilterInit = false;
  rightFilt = 0.0f;
  leftFilt = 0.0f;
}

void drawStandby()
{
  MiniR4.OLED.clearDisplay();
  MiniR4.OLED.setCursor(0, 0);
  MiniR4.OLED.print("Obstacle Challenge");
  MiniR4.OLED.setCursor(0, 10);
  MiniR4.OLED.print("UP: Toggle Dir");
  MiniR4.OLED.setCursor(0, 20);
  MiniR4.OLED.print("DOWN: Start ");
  MiniR4.OLED.print(clockwiseMode ? "CW" : "CCW");
  MiniR4.OLED.display();
}

void finishRun()
{
  delay(1000);
  finished = true;
  stopRobot();
  while (true) {}
}

// =====================================================
// Floor color (blue lap marker)
// =====================================================
FloorColor readFloorColorForLap()
{
  int r = MiniR4.I2C1.MXColorV3.getR();
  int g = MiniR4.I2C1.MXColorV3.getG();
  int b = MiniR4.I2C1.MXColorV3.getB();

  int rgDiff = abs(r - g);
  int rbDiff = abs(r - b);
  int gbDiff = abs(g - b);

  if (rgDiff < 18 && rbDiff < 18 && gbDiff < 18) return FLOOR_UNKNOWN;
  if (b > 100 && b > r && b > g) return FLOOR_BLUE;
  return FLOOR_UNKNOWN;
}

// =====================================================
// Camera parsing
// =====================================================
void clearCamData()
{
  for (int i = 0; i < 10; i++) CamData[i] = 0;
}
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
